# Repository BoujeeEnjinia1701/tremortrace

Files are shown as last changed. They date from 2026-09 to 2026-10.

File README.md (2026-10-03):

# TremorTrace

     

**Area:** BioMedical · **TRL:** 3 of 9 (proof of concept by calculation) · **Value-engineering target:** USD 150 (estimated cost USD 43.79) · **Difficulty:** 2 of 5

Wrist-worn IMU band that logs tremor frequency and amplitude continuously, with an open analysis notebook that produces a daily tremor profile.

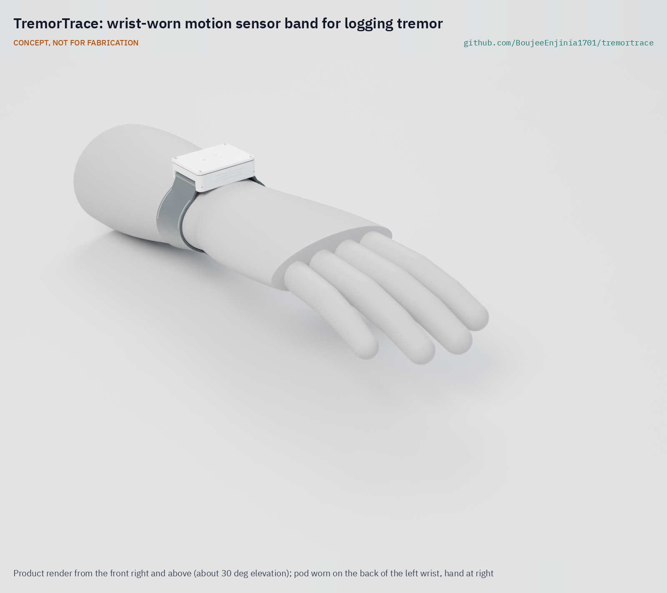
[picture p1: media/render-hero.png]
TremorTrace: wrist-worn motion sensor band for logging tremor, product render


[Exploded render](media/render-exploded.png) · [Detail render](media/render-detail.png) · [Interactive 3D model](media/viewer.html) · [Concept blueprint (PDF)](media/concept-blueprint.pdf) · [General arrangement (PDF)](cad/drawings/TRT-DWG-002.pdf) · [Calculations](docs/04-calcs/01-sizing.md) · [Prototype build plan](docs/05-build-plan.md) · [Design decisions](docs/06-design-decisions.md) · [Review note](docs/REVIEW.md)

## Concept rationale

Research groups have shown that a wrist-worn inertial sensor can follow tremor frequency and amplitude through a normal day, but most of that capability sits inside closed products or a single phone ecosystem. TremorTrace takes the smallest workable path: one off-the-shelf module with a built-in six-axis IMU, a coin-sized cell and a printed pod on a standard 22 mm watch strap. The band reduces each 10 s window to a 32-byte summary and keeps it on the wearer's own devices, so the data volume stays small and the privacy model stays simple.

Being open and garage-buildable matters because the people who most need a daily tremor record, and the researchers who want to study it, rarely control the tools. A design that costs about USD 44 in parts, needs no custom circuit board and publishes its analysis notebook can be built, inspected and adapted by a university lab, a patient group or a maker space anywhere. It is a research and educational prototype, not a medical device.

## Burning platform

Parkinson's disease is growing quickly. The [World Health Organization](https://www.who.int/news-room/fact-sheets/detail/parkinson-disease) estimates that over 8.5 million people were living with it in 2019 and that its prevalence has doubled in the past 25 years. Essential tremor is more common still: a worldwide meta-analysis put its pooled prevalence at 0.9 % at all ages and 4.6 % at age 65 and over ([Louis and Ferreira, Movement Disorders, 2010](https://movementdisorders.onlinelibrary.wiley.com/doi/10.1002/mds.22838)).

The specialists who judge tremor are scarce and unevenly spread. The WHO and World Federation of Neurology atlas found a median of 0.1 neurologists per 100,000 people in low-income countries against 7.1 in high-income countries ([WFN, 2017](https://wfneurology.org/2017-09-18-wcn-press-release-neurology-atlas)). Where a visit comes every few months, or not at all, a short observation in the room is all the evidence there is about how tremor behaves across a day.

## Where it could be used

### By industry

| Industry | Use |
| --- | --- |
| University research | Open, inspectable reference sensor for studies of tremor variation at home |
| Clinical research | Exploratory daily tremor profiles alongside established rating scales and diaries in research studies |
| Patient associations | Low-cost kits for members who want to see and share their own daily patterns |
| Biomedical engineering education | Teaching sampling, spectral analysis, power budgets and privacy-by-design on a real wearable |
| Open hardware and maker spaces | A reproducible wearable platform to adapt for other movement research |

### By country or region

| Country or region | Why it matters there |
| --- | --- |
| Netherlands | ParkinsonNet, founded in 2004, links about 3,000 allied health professionals in 69 regional networks ([Commonwealth Fund, 2016](https://www.commonwealthfund.org/publications/case-study/2016/dec/parkinsonnet-innovative-dutch-approach-patient-centered-care)); community therapists could use shared daily profiles between neurology visits |
| United States | Clinical trials have long used half-hourly home diaries to count daily motor states ([Hauser et al., 2000](https://pubmed.ncbi.nlm.nih.gov/10803796/)); an open sensor record gives researchers a comparison |
| China | A community survey found Parkinson's prevalence of 1.37 % above age 60, about 3.62 million people ([Qi et al., Movement Disorders, 2021](https://movementdisorders.onlinelibrary.wiley.com/doi/10.1002/mds.28762)) |
| Sub-Saharan Africa | The WHO African region reported about 0.1 neurologists per 100,000 people ([WFN, 2017](https://wfneurology.org/2017-09-18-wcn-press-release-neurology-atlas)); a low-cost local record can support the few specialist reviews available |
| India | The burden of non-communicable neurological disorders, Parkinson's disease among them, is rising mainly because the population is ageing, and the national study calls for addressing a shortage of trained neurologists ([ICMR, PHFI and IHME, 2021](https://www.icmr.gov.in/icmrobject/custom_data/1702892885_press_release_gbd_india_neurological_disorders_14072021.pdf)); a band built from widely sold modules suits university and community research groups |

## What sparked the idea

The starting point was the Parkinson's disease home diary developed by Robert Hauser and colleagues in 2000, in which people mark their predominant state for every half hour of the day on paper ([Hauser et al., Clinical Neuropharmacology, 2000](https://pubmed.ncbi.nlm.nih.gov/10803796/)). The diary was built as a patient-reported outcome for clinical trials and is still being validated today ([Löhle et al., npj Parkinson's Disease, 2022](https://www.nature.com/articles/s41531-022-00331-w)), and it shows both how much a day-long record is valued and how much it asks of the person keeping it. TremorTrace asks the same question of a wrist sensor instead: it writes a small entry every 10 seconds without any effort from the wearer and leaves the record in the wearer's hands.

## Problem

Tremor severity is scored during short clinic visits, which misses how it varies day to day.

## Concept

Wrist-worn IMU band that logs tremor frequency and amplitude continuously, with an open analysis notebook that produces a daily tremor profile.

Full design precis: [docs/02-concept.md](docs/02-concept.md)

## Key components

- Seeed XIAO nRF52840 Sense class module (nRF52840 BLE, 6-axis IMU, 2 MB flash, charger)
- 150 mAh protected LiPo cell
- Printed PETG enclosure with TPU gasket, 40 x 30 x 12 mm
- 22 mm woven textile strap, about 8 g

The priced bill of materials (USD 43.79 in parts, against a USD 150 value-engineering target) is in [bom/bom.csv](bom/bom.csv).

## Status at TRL 3

Calculations in [TRT-CAL-001](docs/04-calcs/01-sizing.md) show 0.1 Hz frequency resolution, 4.5 to 6.3 days per charge and 9.7 days of on-band history. Mass is 26.2 g against a 30 g limit with the textile strap adopted under [TRT-DDR-002](docs/decisions/0002-recommendations-accepted.md). The parametric model is [cad/src/model.py](cad/src/model.py) and the general arrangement is [TRT-DWG-002](cad/drawings/TRT-DWG-002.pdf), Rev P3. The design is constructable: every part can be made and fixed as drawn ([TRT-DDR-003](docs/decisions/0003-design-for-construction.md)). TRL 4 work is on hold.

## Building the prototype

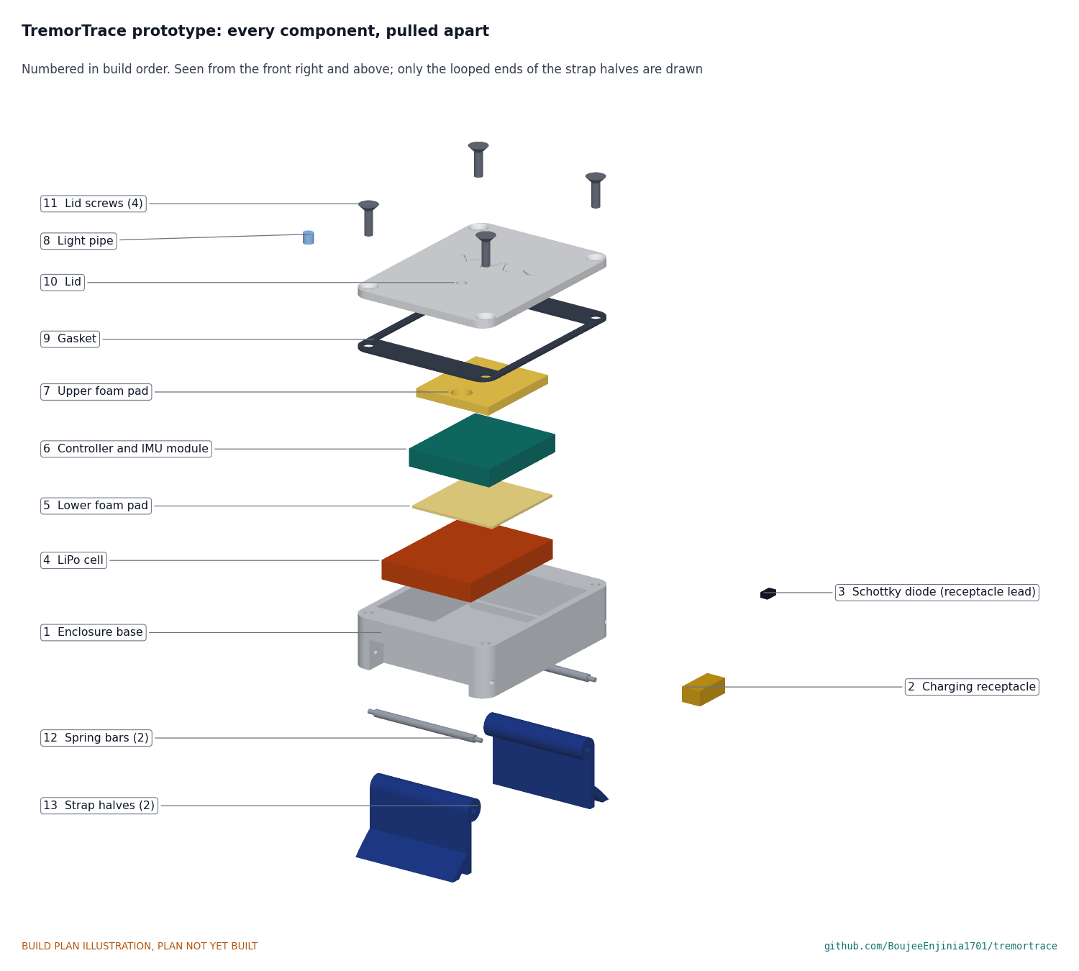
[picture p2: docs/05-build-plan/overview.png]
TremorTrace prototype: every component pulled apart and numbered in build order


The [prototype build plan](docs/05-build-plan.md) (TRT-BLD-001) shows, in pictures, how to make each of the thirteen components and put them together in nine steps; nothing has been built yet. The base, lid and gasket are 3D printed, two foam pads are cut from sheet, and the module, cell, charging receptacle, screws, spring bars and strap are bought; the electronics are four soldered wires and one small diode. Writing the plan made the design buildable: the spring bar holes, lid screws and strap notches were redesigned, and cell ribs, a glue collar for the charging receptacle and foam pads that let the lid clamp the stack were added (TRT-DDR-003, open for Amish's review). Every picture is drawn from the model, and the model checks that each part touches what it should and clears what it should not.

## Safety

> This is a research and educational prototype. It is not a medical device, has not been cleared or approved by any regulator, and must not be used to diagnose, treat or monitor any person.

## Repository layout

| Folder | Contents |
| --- | --- |
| `docs/` | Problem, concept, requirements, calculations, build plan and design decisions |
| `cad/src/` | build123d Python source, the source of truth for all geometry |
| `cad/step/`, `cad/stl/` | Exported models for FreeCAD, other CAD tools and printing |
| `cad/drawings/` | 2D sketches and dimensioned drawings |
| `bom/` | Bill of materials |
| `electronics/` | KiCad schematics and PCB layouts |
| `firmware/` | Microcontroller code |
| `media/` | Renders, perspectives and photos |
| `build-log/` | Dated prototyping notes |

## Documentation

Controlled documents follow the portfolio [documentation standard](.kit/STANDARDS.md). Each carries a document ID (TRT-PRC-001 for the precis), a version and a revision history. Branded PDFs are built with `python .kit/render.py` and attached to GitHub Releases when a document is tagged, for example `TRT-PRC-001/v1.0`.

## Credits

Designed by Amish Chadha, with contributions from Dr. Geeti Chadha. See [CONTRIBUTORS.md](CONTRIBUTORS.md) for roles. To cite this design, use [CITATION.cff](CITATION.cff) (GitHub shows it as "Cite this repository").

AI assistance (Claude) was used to accelerate concept renders, prototype documentation and first-pass sizing calculations. Design direction and all decisions are Amish Chadha's, recorded in this repository's decision records (`docs/decisions/`).

## Licenses

- **Hardware** (CAD, drawings, BOM, electronics): [CERN-OHL-S v2](LICENSE)
- **Software** (firmware, scripts, notebooks): [MIT](LICENSE-SOFTWARE)

A project of the [Design Molecule](https://designmolecule.com) lab.

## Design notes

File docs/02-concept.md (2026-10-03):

---
doc_id: TRT-PRC-001
title: TremorTrace design precis
project: TremorTrace
doc_type: Design precis
version: "0.8"
status: Draft
date: '2026-10-02'
author: Amish Chadha
license: CERN-OHL-S-2.0
revisions:
- version: "0.1"
  date: '2026-09-24'
  author: Amish Chadha
  change: Initial scaffold
- version: "0.2"
  date: '2026-09-24'
  author: Amish Chadha
  change: Populate to TRL 2 (architecture, first-order numbers, safety, media)
- version: "0.3"
  date: '2026-09-24'
  author: Amish Chadha
  change: 'Review fixes: one-module and local-first choices marked proposed; massing pod closed at 12 mm; concept sheet renumbered TRT-DWG-001'
- version: "0.4"
  date: '2026-09-25'
  author: Amish Chadha
  change: 'TRL 3: decisions from TRT-DDR-001 recorded; numbers from TRT-CAL-001 (storage ratio 390, not 1,000; firmware in internal flash; mass 29.4 g); parametric model and TRT-DWG-002'
- version: "0.5"
  date: '2026-09-25'
  author: Amish Chadha
  change: Recommendations accepted by Amish (DDR-002)
- version: "0.6"
  date: '2026-10-02'
  author: Amish Chadha
  change: 'Design for construction (TRT-DDR-003): lid screws, base features, mass and cost; budget as a value-engineering target'
- version: "0.7"
  date: '2026-10-02'
  author: Amish Chadha
  change: First partner and the activity-flag question answered by Amish's decisions of 2026-10-02 (TRT-DEC-001)
- version: "0.8"
  date: '2026-10-02'
  author: Amish Chadha
  change: 'Parts cost USD 43.79 with the Schottky diode (BOM line 12)'
---

# TremorTrace design precis

TremorTrace is a small wrist pod on a watch strap that records wrist motion all day, turns it into 10-second tremor summaries on the band, and hands them to an open notebook that draws a daily tremor profile. The TRL 3 calculations (TRT-CAL-001) show that one off-the-shelf module and a 150 mAh cell meet nine of eleven requirements for USD 43.79 in parts, including mass at 26.2 g against a 30 g limit with a textile strap; splash resistance and the notebook can only be verified with hardware and software work.

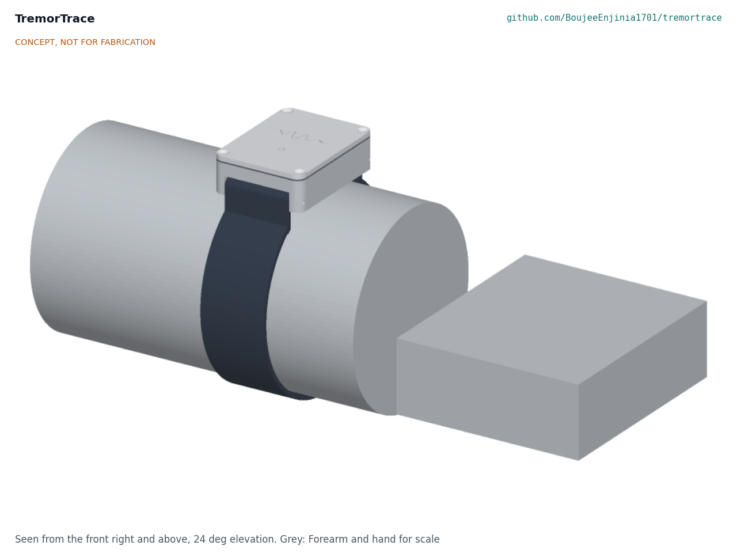
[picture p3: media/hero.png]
Hero render


## How it works

1. **Sense.** A 6-axis IMU (accelerometer and gyroscope) samples wrist motion at 104 Hz, with ranges of +/-8 g and +/-2000 dps.
2. **Summarize on the band.** Every 10 seconds the firmware band-pass filters the signal to 3 to 15 Hz, runs a spectrum, and stores a 32-byte summary: dominant frequency, band RMS of acceleration and angular velocity, total RMS, a band-to-low-frequency power ratio and an activity flag. Tremor values are kept even when the flag says the wearer was moving, so tremor during activity is not lost.
3. **Store.** Summaries go to the module's 2 MB flash, enough for 9.7 days at 16 h of wear per day without a phone. A 256 kB area holds up to 21 raw 10 s snippets captured on demand for research.
4. **Sync.** When the owner opens the web Bluetooth page or a laptop script, summaries transfer over Bluetooth Low Energy. Nothing goes to the cloud.
5. **Analyze.** An open Python notebook turns summaries into a daily profile: minutes of tremor per hour, dominant frequency and amplitude over the day, and optional medication-time markers entered by the owner.

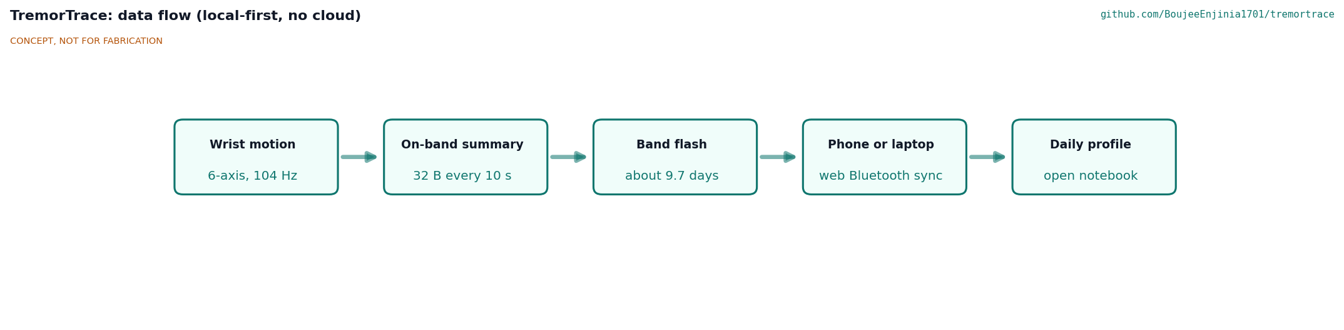
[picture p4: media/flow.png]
System and data flow


## Main components

Table 1. Main components; item numbers match `bom/bom.csv` and the exploded view.

| # | Component | Choice | Notes |
| --- | --- | --- | --- |
| 1 | Strap | 22 mm woven textile two-piece quick-release strap | Skin-safe and washable; the heaviest part (about 8 g, assumed). Replaced the 12 g silicone strap; decided by Amish, 2026-09-25 (TRT-DDR-002) |
| 2 | Enclosure lid | 3D-printed PETG, 1.5 mm, four M2 countersunk screws, one in each lug horn | 2 mm light pipe over the module's status LED |
| 3 | Controller and IMU | Seeed XIAO nRF52840 Sense class: nRF52840, LSM6DS3TR-C IMU, 2 MB flash, BQ25101 charger | One module, no custom PCB. Decided by Amish, 2026-09-25 (TRT-DDR-001) |
| 4 | Battery | 150 mAh protected LiPo, 19.75 x 26.02 x 3.8 mm (Adafruit 1317 class) | See power budget |
| 5 | Enclosure base | 3D-printed PETG with integrated 22 mm lugs, cell locating ribs and a glue collar | Charging connector glued through the floor |
| 6 | Charging contacts | Magnetic 2-pin pogo connector | Keeps the enclosure sealed |
| 7 | Gasket | Printed TPU ring, 0.5 mm compressed | Toward the IP54 target (R7) |
| 8 | Spring bars | 22 mm | Hold the strap in the lugs |

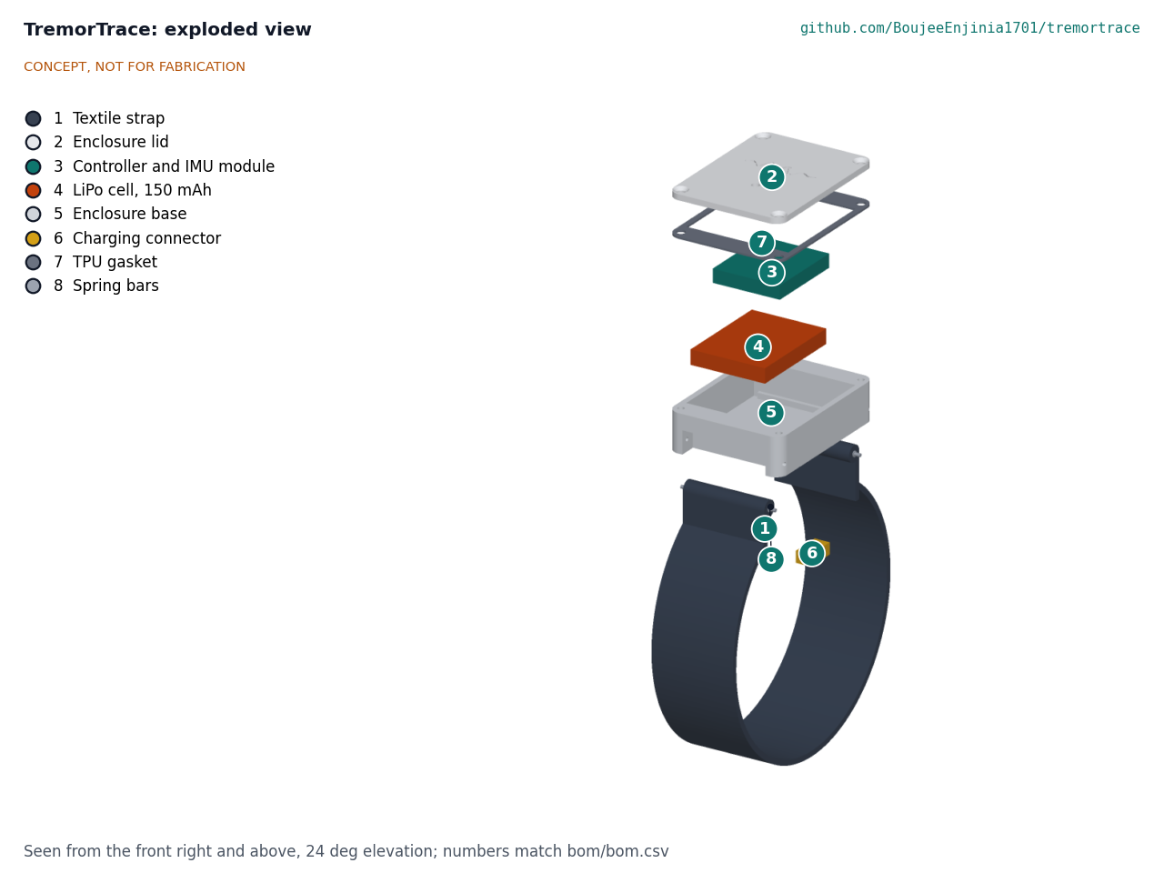
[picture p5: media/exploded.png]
Exploded view


## Key numbers

All values come from TRT-CAL-001 and the parametric model in `cad/src/model.py`.

Table 2. Key numbers at TRL 3.

| Quantity | Value | Requirement |
| --- | --- | --- |
| Frequency resolution | 0.100 Hz bins (10 s at 104 Hz) | R1 (0.2 Hz) met, with sample-rate correction |
| Nyquist limit | 52 Hz | R1, R3 met |
| In-band noise | 0.31 mg and 0.017 dps RMS | R2 met |
| Recording current | 1.12 mA nominal, 1.54 mA conservative | |
| Battery life | 6.3 days nominal, 4.5 days conservative | R4 (3 days) met, if the firmware sleeps |
| Summary storage | 184.3 kB per day (32 bytes per 10 s, 16 h) | |
| On-band history | 9.7 days | R5 (7 days) met |
| Pod size | 40 x 30 x 12 mm | R6 size met |
| Mass | 26.2 g with textile strap | R6 (30 g) met, 3.8 g margin |
| Parts cost | USD 43.79, USD 106.21 under the USD 150 value-engineering target | R10 met |

The general arrangement is drawing TRT-DWG-002 (`cad/drawings/TRT-DWG-002.pdf`), Rev P3. How to build the prototype is in the build plan TRT-BLD-001 (`docs/05-build-plan.md`); the changes that made the design buildable are in TRT-DDR-003.

## Key design choices

- **Summaries, with optional raw snippets.** A 32-byte summary is 390 times smaller than the 12,480 bytes of raw data in a 10 s window, and it keeps personal data minimal. Decided by Amish, 2026-09-25 (TRT-DDR-001).
- **One module, no custom PCB.** Keeps the first build within reach of anyone with a soldering iron and a 3D printer. Decided by Amish, 2026-09-25 (TRT-DDR-001).
- **Web Bluetooth page first.** No app store and no account; a native app may follow. Decided by Amish, 2026-09-25 (TRT-DDR-001).
- **Local-first data.** No cloud account is needed to use or analyze the data (R9). Decided by Amish, 2026-09-25 (TRT-DDR-001).
- **Most affected wrist first.** Decided by Amish, 2026-09-25 (TRT-DDR-001).
- **Charge current 50 mA.** Charges in about 3.6 h with about 65 mW of charger heat, against 1.8 h and 130 mW at 100 mA. The firmware selects the 50 mA setting. Decided by Amish, 2026-09-25 (TRT-DDR-002).
- **Textile strap.** A woven textile strap of about 8 g replaces the 12 g silicone strap and raised the R6 mass margin from 0.6 g to 4.6 g (3.8 g after the parts added for construction). Decided by Amish, 2026-09-25 (TRT-DDR-002).

## Safety

> **Safety:** Research and educational prototype only. It is not a medical device, has not been cleared or approved by any regulator, and must not be used to diagnose, treat or adjust medication.

- The LiPo cell sits against the skin: use a protected cell, never charge while worn, charge at no more than the cell's 150 mA limit, and stop use if the pod becomes warm or swollen.
- Use skin-safe strap materials and check for irritation during long wear.
- Tremor data is health data. Keep it on the owner's devices and share only with consent.

## Open questions

- The activity flag marks tremor during a reach as activity in synthetic data (TRT-CAL-001, section 4). How well can action tremor be separated from voluntary movement with 10 s summaries? Decided by Amish, 2026-10-02: keep the flag, report tremor with and without it, and choose a classifier at TRL 4 from recorded data.
- Confirm the IMU sample-rate tolerance, the module's run current and the textile strap mass.
- First clinical or patient partner for co-design and eventual validation. Decided by Amish, 2026-10-02 (TRT-DEC-001): the first candidate to approach is an academic movement disorders clinic with its own ethics board, introduced through the OpenRatio network, with the International Essential Tremor Foundation as the route to participants, shared with StillBand and SteadySleeve; not yet approached.

Open decisions are tracked in the design decisions register, TRT-DEC-001 (`docs/06-design-decisions.md`).

Concept media: [blueprint sheet](../media/concept-blueprint.pdf), [interactive 3D model](../media/viewer.html).

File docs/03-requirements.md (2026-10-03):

---
doc_id: TRT-REQ-001
title: TremorTrace requirements
project: TremorTrace
doc_type: Requirements
version: "0.6"
status: Draft
date: '2026-10-02'
author: Amish Chadha
license: CERN-OHL-S-2.0
revisions:
- version: "0.1"
  date: '2026-09-24'
  author: Amish Chadha
  change: Initial scaffold
- version: "0.2"
  date: '2026-09-24'
  author: Amish Chadha
  change: First measurable requirements for TRL 2
- version: "0.3"
  date: '2026-09-25'
  author: Amish Chadha
  change: 'Apply TRT-DDR-001 decisions: R5 redefined with a raw-snippet reserve, R11 names the LED and web Bluetooth page, wrist choice; status from TRT-CAL-001'
- version: "0.4"
  date: '2026-09-25'
  author: Amish Chadha
  change: Recommendations accepted by Amish (DDR-002)
- version: "0.5"
  date: '2026-10-02'
  author: Amish Chadha
  change: 'Design for construction (TRT-DDR-003): R6 and R10 figures; budget as a value-engineering target'
- version: "0.6"
  date: '2026-10-02'
  author: Amish Chadha
  change: 'R10 cost restated with the Schottky diode (USD 43.79); no status changed'
---

# TremorTrace requirements

These requirements were checked by calculation in TRT-CAL-001 (TRL 3). Nine are met by calculation or design review and R7 and R8 cannot be verified on paper; none is not met. Changes in v0.3 follow Amish's decisions of 2026-09-25 (TRT-DDR-001). In v0.4, R6 moves from at risk to met because the textile strap recommended at TRL 3 was accepted (TRT-DDR-002), and R4 names the 50 mA charge setting. In v0.5 the mass and cost figures follow the constructable design (TRT-DDR-003) and the budget is treated as a value-engineering target; no status changes.

Table 1. Requirements and TRL 3 status.

| ID | Requirement | Target | Verification (TRL 3 or later) | TRL 3 status (TRT-CAL-001) |
| --- | --- | --- | --- | --- |
| R1 | Measure tremor frequency across the clinically relevant band | 3 to 15 Hz, resolution 0.2 Hz or better | Calculation of sampling and window length; later bench shaker test | Met, if the firmware corrects the sample rate against the crystal |
| R2 | Measure tremor amplitude | Acceleration RMS and angular velocity RMS in the tremor band, reported per window | Calculation; later comparison against a reference sensor | Met |
| R3 | Sample motion fast enough | 6-axis IMU at 100 Hz or more | Datasheet and firmware configuration | Met |
| R4 | Run a full waking day and more | 3 days or more between charges at 16 h per day of wear; recharge at the 50 mA setting | Power budget calculation | Met, 4.5 to 6.3 days, if the firmware sleeps |
| R5 | Store a week of results on the band | 7 days of 10 s window summaries at 16 h of wear per day without a phone, alongside a reserved area for on-demand raw snippets | Storage calculation | Met, 9.7 days |
| R6 | Comfortable for all-day wear | Mass 30 g or less including strap; pod no larger than 45 x 35 x 14 mm | Massing model, then weighing | Met: 26.2 g with textile strap (TRT-CAL-001 v0.3); size met |
| R7 | Skin-safe and wearable | Silicone or textile strap; no exposed electronics; splash resistant (IP54 target) | Design review | Not verifiable at TRL 3 |
| R8 | Produce a daily tremor profile | Open notebook turning window summaries into a daily chart of tremor time, frequency and amplitude | Run on sample data | Not verifiable at TRL 3 |
| R9 | Protect health data | Data stored locally and exported only by the owner; no cloud dependency | Design review | Met (design review) |
| R10 | Low cost and buildable | Parts cost reported against the USD 150 value-engineering target; no custom PCB required for the first build | Priced BOM | Met: USD 43.79, USD 106.21 under the target |
| R11 | Clear status | Status LED on the band and the web Bluetooth page show battery, recording and sync state | Design review | Met (design review) |

## Assumptions

- Parkinsonian rest tremor is typically about 4 to 6 Hz and essential tremor about 4 to 12 Hz; a 3 to 15 Hz band covers both with margin.
- Wear time of 16 h per day and nightly charging is acceptable, but a multi-day battery is preferred so a missed charge does not lose a day.
- One band is worn on the most affected wrist (decided by Amish, 2026-09-25, TRT-DDR-001); both wrists are later work.
- The mass limit in R6 includes the strap. The strap is a woven textile strap of about 8 g (TRT-DDR-002) and remains the least certain item in the mass estimate.

> **Safety:** TremorTrace is a research and educational prototype, not a medical device. It carries a lithium polymer cell against the skin; the cell must be protected and must never be charged while the band is worn.

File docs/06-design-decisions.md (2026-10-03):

---
doc_id: TRT-DEC-001
title: TremorTrace design decisions register
project: TremorTrace
doc_type: Design decisions register
version: "0.3"
status: Draft
date: '2026-10-02'
author: Amish Chadha
license: CERN-OHL-S-2.0
revisions:
- version: "0.1"
  date: '2026-10-02'
  author: Amish Chadha
  change: Register opened; open decisions from the review note, the decision records and the build plan work
- version: "0.2"
  date: '2026-10-02'
  author: Amish Chadha
  change: Amish approved the recommendations for open items 1 to 10 on 2026-10-02 (TRT-DDR-003 accepted, with A1 and A2); moved to decisions made
- version: "0.3"
  date: '2026-10-02'
  author: Amish Chadha
  change: 'Cost restated with the diode (BOM line 12): USD 43.79'
---

# TremorTrace design decisions register

Every design decision still to be made, and every decision made, in one place. Each decision is argued in full in its decision record under `docs/decisions/` or in the review note (`docs/REVIEW.md`); this register is the index Amish works from. The build plan (`docs/05-build-plan.md`) describes the design as it stands and does not list open decisions.

> **Safety:** TremorTrace is a research and educational prototype, not a medical device. It has not been cleared or approved by any regulator and must not be used to diagnose, treat or monitor any person.

## Open decisions

None. All open decisions were decided on 2026-10-02.

## To confirm when parts are bought

| # | What to confirm | Why it matters | Source |
| --- | --- | --- | --- |
| 1 | The status LED position on the module | It sets the light pipe bore (6.5 mm from the centre on the centre line) and the hole in the upper foam pad | TRT-DDR-003, C6 and C8 |
| 2 | The module's thickness with its components (3.5 mm assumed) | It sets the squeeze on the upper foam pad; more than 4.5 mm would need a thinner pad | TRL 3 model; TRT-CAL-001, section 7 |
| 3 | The charging receptacle's body size (4 x 8 x 3 mm assumed) and whether it has a flange | It sets the floor opening and the glue collar | TRT-DDR-003, C4 |
| 4 | The spring bars' tip diameter (about 0.9 mm) | The horn holes are drilled 1.0 mm; tips over 1.0 mm need a larger drill | TRT-DDR-003, C1 |
| 5 | That the module's 5 V pin carries no voltage with the cell connected and no charger | The receptacle contacts touch the skin; a Schottky diode is fitted in any case (decided 2026-10-02), and this check decides whether it can ever be dropped | TRT-DDR-003, A2 |
| 6 | That a printed horn takes an M2 thread-forming screw without splitting (1.2 mm of plastic round the screw) | If it splits, print the horns hotter or use M1.6 screws | TRT-DDR-003, C2 |
| 7 | The textile strap's mass (8 g assumed) and that its ends loop round a 1.5 mm bar inside a 4.5 mm notch | Mass margin under R6 is 3.8 g; the loop clearance is 0.35 mm | TRT-CAL-001, section 7; TRT-DDR-003, C3 |
| 8 | The IMU sample-rate tolerance and the module's run current | They carry the R1 and R4 results | TRT-CAL-001, sections 2 and 5 |

## Value engineering

Value-engineering target: USD 150 (a hypothetical control target, not a limit). Estimated cost of the constructable design: USD 43.79 (USD 106.21 under the target). Main cost drivers and savings worth trying:

- The largest lines are the controller and IMU module (USD 15.99), the textile strap (USD 10.00), the magnetic charging receptacle with its cable (USD 6.00) and the LiPo cell (USD 5.95); together they are USD 37.94 of the USD 43.79.
- Making the design constructable added USD 0.50 (two more lid screws); the foam pads and epoxy fall within the existing consumables allowance.
- Savings worth trying: a generic 22 mm textile strap (often under USD 5); buying the charging receptacle and cable as a bulk pair; the module price in small quantities from a distributor.

## Decisions made

| Date | Decision | Decided by | Record |
| --- | --- | --- | --- |
| 2026-09-25 | D1 single nRF52840 module with built-in IMU, no custom PCB; D2 10 s summaries with optional raw snippets; D3 web Bluetooth page first; D4 most affected wrist first; D5 local-first data | Amish: "proceed with all of your recommendations across all batches. Make sure we don't proceed to TRL 4 on any of them." | TRT-DDR-001 |
| 2026-09-25 | D6 charge at the 50 mA setting; D7 woven textile strap of about 8 g | Amish: "i accept all your recommendations, go with them across all repos." | TRT-DDR-002 |
| 2026-09-30 | Make the design physically buildable while drawing the build plan; keep open decisions out of the build plan | Amish: "If you are realising that the design cannot be built as per concept - fix the design assumptions to match and be physically feasible as you draw the illustrations." The changes were accepted on 2026-10-02 (below) | TRT-DDR-003 |
| 2026-10-01 | Treat `budget_usd` as a value-engineering target, not a limit | Amish: "the budgets are a hypothethical control target to ensure we are thinking along a value engineering lens" | `.kit/STANDARDS.md`, section 18 |
| 2026-10-02 | Design for construction accepted: the changes C1 to C9 of TRT-DDR-003, as made | Amish: "APPROVED: The open decisions from the last wave (TremorTrace to ZeerBox) came in after the review and aren't on the page either." | TRT-DDR-003, Table 1 |
| 2026-10-02 | Firmware update route: over Bluetooth with the nRF52840's over-the-air bootloader; opening the pod, with a new gasket, is kept for recovery only | Amish: "APPROVED: The open decisions from the last wave (TremorTrace to ZeerBox) came in after the review and aren't on the page either." | TRT-DDR-003, A1 |
| 2026-10-02 | Skin-side charging contacts: a small Schottky diode is fitted in the receptacle's positive lead on every band, and the bought module's 5 V pin is still checked dead with the cell connected and no charger; the diode is dropped only if measurements show the pin dead in every operating state | Amish: "APPROVED: The open decisions from the last wave (TremorTrace to ZeerBox) came in after the review and aren't on the page either." | TRT-DDR-003, A2 |
| 2026-10-02 | First co-design and validation partner: the first candidate to approach is an academic movement disorders clinic with its own ethics board, introduced through the OpenRatio network, with the International Essential Tremor Foundation as the route to participants, shared with StillBand and SteadySleeve. No prototype is worn without clinical oversight and ethics approval | Amish: "APPROVED: The open decisions from the last wave (TremorTrace to ZeerBox) came in after the review and aren't on the page either." | TRT-DDR-001, O1; TRT-DDR-002 |
| 2026-10-02 | OpenRatio confirmed as a named possible partner, described in soft, non-clinical wording as a research and educational network, not a clinical service | Amish: "APPROVED: The open decisions from the last wave (TremorTrace to ZeerBox) came in after the review and aren't on the page either." | TRT-DDR-001, O2 |
| 2026-10-02 | Kit 1.3.1 approved: concept media for small objects show a forearm for scale instead of the 1.75 m person | Amish: "APPROVED: The open decisions from the last wave (TremorTrace to ZeerBox) came in after the review and aren't on the page either." | TRT-DDR-001, O3 |
| 2026-10-02 | Strap path: the circular strap stays in the parametric model for the drawing and mass; the elliptical wrist path is used in renders only | Amish: "APPROVED: The open decisions from the last wave (TremorTrace to ZeerBox) came in after the review and aren't on the page either." | `docs/REVIEW.md`, 2026-09-26, item 1 |
| 2026-10-02 | Lid mark and grip ribs kept as printed-in features at no cost, with the mark debossed 0.4 mm (two 0.2 mm layers) into the 1.5 mm lid | Amish: "APPROVED: The open decisions from the last wave (TremorTrace to ZeerBox) came in after the review and aren't on the page either." | `docs/REVIEW.md`, 2026-09-26, item 3 |
| 2026-10-02 | Module detail and charging lead in the renders accepted as illustration only | Amish: "APPROVED: The open decisions from the last wave (TremorTrace to ZeerBox) came in after the review and aren't on the page either." | `docs/REVIEW.md`, 2026-09-26, item 4 |
| 2026-10-02 | Tremor during a reach: the separate activity flag is kept and tremor is reported both with and without it; a classifier is chosen at TRL 4 from recorded data | Amish: "APPROVED: The open decisions from the last wave (TremorTrace to ZeerBox) came in after the review and aren't on the page either." | TRT-CAL-001, section 4; TRT-PRC-001 |

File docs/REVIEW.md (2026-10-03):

# Review note: TremorTrace

## Session 2026-09-24: /populate to a strong TRL 2 (pilot run from Cowork)

### What was done

- `docs/01-problem.md` (TRT-PRB-001 v0.2): users and context, constraints, out of scope, prior research with links.
- `docs/03-requirements.md` (TRT-REQ-001 v0.2): 11 measurable requirements (R1 to R11) with targets and planned verification.
- `docs/02-concept.md` (TRT-PRC-001 v0.2): how it works, main components, first-order numbers, design choices, safety, open questions.
- `cad/src/concept_media.py`: massing model (strap, enclosure, module, LiPo cell, contacts) with a forearm and hand for scale.
- `media/`: hero, blueprint sheet (PNG and PDF), cutaway, exploded view with BOM callouts, data flow diagram, `model.glb` and `viewer.html`.
- `bom/bom.csv`: seven lines with indicative prices, numbered to match the exploded view; `bom/bom-notes.md`.
- `docs/pdf/`: branded PDFs of the three controlled documents.

### Key results (estimates, to be checked at TRL 3)

| Quantity | Estimate | Requirement |
| --- | --- | --- |
| Frequency resolution | 0.1 Hz (10 s window at 104 Hz) | R1 met |
| Battery life | about 4 days on 150 mAh | R4 met, thin margin |
| On-band history | about 10 days of summaries | R5 met |
| Mass | about 22 g with strap | R6 met |
| Parts cost | about $40 | R10 met |

No requirement is known to be missed. R4 depends on IMU current in the chosen module, which is unverified.

### Proposed, awaiting Amish

1. Controller: a single nRF52840 module with built-in IMU (Seeed XIAO nRF52840 Sense class). Alternative: separate nRF52 module and IMU breakout (more wiring, more flexibility). Decided by Amish, 2026-09-25: go with recommendation (TRT-DDR-001).
2. Store 10-second summaries rather than raw data, with optional raw snippets for research. Decided by Amish, 2026-09-25: go with recommendation (TRT-DDR-001).
3. Phone route: a web Bluetooth page first, native app later. Decided by Amish, 2026-09-25: go with recommendation (TRT-DDR-001).
4. Wear on the most affected wrist first; both wrists later. Decided by Amish, 2026-09-25: go with recommendation (TRT-DDR-001).
5. First co-design and validation partner: a movement disorders clinic, a patient association, or the OpenRatio network.

### Safety concerns

- Not a medical device; the documents say so and must keep saying so.
- LiPo cell against skin: protected cell, no charging while worn.
- Tremor data is health data: local-first design, owner-controlled sharing.

### Recommended next step

Review this note and the media. If approved, run `/advance-trl3` to verify the power budget, frequency analysis and activity flag by calculation and produce the parametric model and drawing sheet.

## Session 2026-09-24: review fixes

At Amish's request, after a review of commits `15c42b7` and `5091eea`:

- `cad/src/concept_media.py`: the massing pod had no side walls between base and lid, and stacked to 13.5 mm against the 12 mm in TRT-PRC-001. The base walls now enclose the cell and module, and the pod is 12.0 mm overall. All media regenerated.
- The concept sheet is renumbered TRT-DWG-001 (it was TRT-DWG-010); drawing numbers start at 001 (`.kit/STANDARDS.md`, section 1).
- TRT-PRC-001 v0.3: "One module, no custom PCB" and "Local-first data" are now marked "Proposed, awaiting Amish", as `CLAUDE.md` section 2 requires.

Still awaiting Amish: approval of kit 1.3.1, whose forearm-for-scale rule for small objects replaces the 1.75 m person that `/populate` asks for, and confirmation of "OpenRatio" as a possible co-design partner.

## Session 2026-09-25: TRL 3

Authority: on 2026-09-25 Amish wrote "proceed with all of your recommendations across all batches. Make sure we don't proceed to TRL 4 on any of them." This session advanced TremorTrace from TRL 2 to TRL 3 and stopped there.

### What was done

- `docs/decisions/0001-trl2-review-decisions.md` (TRT-DDR-001 v0.1): the TRL 2 review decisions, and the items still open.
- `docs/04-calcs/01-sizing.md` (TRT-CAL-001 v0.1) and `docs/04-calcs/sizing.py`: sampling, noise and range, a synthetic check of the 10 s window algorithm and the activity flag, power budget, storage, size and mass (read from the model), and cost (read from the BOM).
- `cad/src/model.py`: parametric build123d model (pod base with integrated 22 mm lugs, gasket, lid, cell, module, charging connector, spring bars, strap). Exports `cad/step/tremortrace-{pod-assembly,on-strap,base,lid,gasket}.step` and `cad/stl/tremortrace-{pod-assembly,base,lid,gasket}.stl`.
- `cad/src/sheets.py` and `cad/drawings/TRT-DWG-002.{svg,pdf,png}`: general arrangement at Rev P1, 2:1, marked "CONCEPT, NOT FOR FABRICATION" and "PRELIMINARY, NOT FOR FABRICATION".
- `bom/bom.csv`: 11 lines, every line priced, $41.19 per band; `bom/bom-notes.md` updated.
- `cad/src/concept_media.py` now builds the media from `model.py`; all media regenerated and inspected (hero, blueprint TRT-DWG-001, cutaway, exploded view with items 1 to 8, flow, `model.glb`).
- TRT-REQ-001 v0.3, TRT-PRB-001 v0.3 and TRT-PRC-001 v0.4 updated for the decisions and the calculated numbers. The precis was already at v0.3, so it moved to v0.4 rather than 0.3.
- `project.yaml`: `trl: 3`, `trl_target: 3`, evidence listed. `README.md`: TRL 3 badge and status.

### Requirement status (TRT-CAL-001)

Not met: none. At risk and not verifiable first:

| ID | Status | Value |
| --- | --- | --- |
| R6 | At risk (mass); size met | 29.4 g against 30 g, strap assumed 12 g; pod 40 x 30 x 12 mm |
| R7 | Not verifiable at TRL 3 | Gasketed pod; IP54 needs a test |
| R8 | Not verifiable at TRL 3 | Summary record defined; notebook not written |
| R1 | Met, conditional | 0.100 Hz bins; needs sample-rate correction against the 32.768 kHz crystal (up to 0.30 Hz error otherwise) |
| R4 | Met, conditional | 6.3 days nominal, 4.5 days conservative; 0.69 days if the firmware never sleeps |
| R5 | Met | 9.7 days; 6.4 days if the band logged 24 h per day |
| R2, R3, R9, R10, R11 | Met | Noise floor 0.31 mg RMS; 104 Hz; local-first; $41.19; LED and web Bluetooth page |

Corrections to TRL 2 numbers: the summary-to-raw ratio is 390, not about 1,000; firmware sits in the nRF52840's internal flash, so all 2 MB of external flash holds data; the mass estimate rose from 22 g to 29.4 g once the enclosure was modeled (7.0 g, not 5 g) and the cell mass taken from its listing (4.65 g).

Finding: the simple activity flag (low-frequency power greater than tremor-band power) marks tremor during a reach as activity in synthetic data, which would undercount action tremor in essential tremor. The design now keeps tremor values in every record and stores the flag separately.

### Decisions recorded (TRT-DDR-001)

Decided by Amish, 2026-09-25, going with the recommendation: D1 single nRF52840 module with built-in IMU, no custom PCB; D2 summaries with optional raw snippets; D3 web Bluetooth page first; D4 most affected wrist first; D5 local-first data. No budget or pitch change was recommended, so `budget_usd` stays at 150 and the pitch is unchanged.

### Still awaiting Amish

1. First co-design and validation partner (clinic, patient association or OpenRatio network). No recommendation was made.
2. Confirmation of OpenRatio as a possible partner.
3. Approval of kit 1.3.1 (forearm-for-scale rule for small objects). No recommendation was stated.
4. New: charge current 50 mA (recommended; 0.33 C, about 65 mW charger heat) or 100 mA. Decided by Amish, 2026-09-25: go with recommendation (TRT-DDR-002).

### Safety concerns

- Not a medical device; every document says so.
- LiPo cell against the skin: protected cell, never charge while worn, charge at or below the cell's 150 mA limit. The linear charger dissipates about 65 mW at 50 mA and 130 mW at 100 mA inside a sealed pod.
- Tremor data is health data; the design has no cloud path.

### Citations

The TRL 2 note listed no unchecked citations. This session checked the LSM6DS3TR-C figures (ST product page and datasheet), the XIAO nRF52840 figures (Seeed wiki) and the Adafruit 1317 cell (product page) on the web and cites them in TRT-CAL-001, section 9. The XIAO unit price could not be confirmed and stays indicative. Values marked "assumed" in TRT-CAL-001 have no source.

### TRL 4 material

None found. `build-log/` holds only its README; `electronics/` and `firmware/` are empty.

### Recommended next step

TRL 4 is on hold by Amish's instruction; do not start it. Paper work that remains within TRL 3: decide the four open items above, and choose a lighter strap (textile, about 8 g) to restore mass margin under R6 if Amish agrees. Decided by Amish, 2026-09-25: go with recommendation (TRT-DDR-002).

For reference only, TRL 4 would need: a built band, a bench shaker test of frequency and amplitude against a reference sensor (R1, R2), a measured current profile (R4), a splash test (R7), the analysis notebook run on recorded data (R8), weighing (R6), a lab test report (TST with `environment: lab`) and build log entries.

## Session 2026-09-25: recommendations accepted

Authority: on 2026-09-25 Amish wrote "i accept all your recommendations, go with them across all repos." Every open item with a recommendation is now "Decided by Amish, 2026-09-25: go with recommendation" and is recorded in `docs/decisions/0002-recommendations-accepted.md` (TRT-DDR-002 v0.1).

### Decisions applied and what changed

| # | Decision | Before | After |
| --- | --- | --- | --- |
| D6 | Charge current 50 mA (was TRT-DDR-001 O4) | Proposed, 50 or 100 mA | 50 mA as a firmware rule; about 3.6 h, about 65 mW charger heat |
| D7 | Woven textile strap, 22 mm | Silicone, 12 g, $8.00, 2.5 mm thick in the model | Textile, 8 g, $10.00, 1.4 mm thick in the model |
| | Resulting mass (R6) | 29.4 g, 0.6 g margin, at risk | 25.4 g, 4.6 g margin, met |
| | Parts cost (R10) | $41.19 | $43.19 |
| | Budget (`project.yaml`) | $150 | $150 (no change recommended) |

Files changed: `bom/bom.csv`, `bom/bom-notes.md`, `cad/src/model.py` (STEP and STL re-exported), `cad/src/sheets.py` (TRT-DWG-002 Rev P1 to P2), `cad/src/concept_media.py` (media regenerated), `docs/04-calcs/sizing.py`, TRT-CAL-001 v0.1 to v0.2, TRT-REQ-001 v0.3 to v0.4, TRT-PRC-001 v0.4 to v0.5, TRT-DDR-001 v0.1 to v0.2 (O4 marked decided), new TRT-DDR-002 v0.1, `project.yaml` (DDR-002 added to TRL evidence), `README.md`.

Also in this session: all generated files (document PDFs, drawing sheets, concept media) were regenerated so the footers carry designmolecule.com, and the README gained the sections "Concept rationale", "Burning platform", "Where it could be used" and "What sparked the idea". The inspiration point is the Parkinson's disease home diary of Hauser et al. (2000), with cited sources.

### Requirement status (TRT-CAL-001 v0.2)

Not met: none. At risk: none.

| ID | Status | Value |
| --- | --- | --- |
| R7 | Not verifiable at TRL 3 | Gasketed pod; IP54 needs a test |
| R8 | Not verifiable at TRL 3 | Summary record defined; notebook not written |
| R1 | Met, conditional | 0.100 Hz bins; needs sample-rate correction against the crystal |
| R4 | Met, conditional | 6.3 days nominal, 4.5 days conservative, if the firmware sleeps |
| R6 | Met | 25.4 g against 30 g; pod 40 x 30 x 12 mm |
| R2, R3, R5, R9, R10, R11 | Met | 0.31 mg noise floor; 104 Hz; 9.7 days; local-first; $43.19; LED and web Bluetooth page |

### Still awaiting Amish (no recommendation was made)

1. O1: first co-design and validation partner (clinic, patient association or OpenRatio network).
2. O2: confirmation of OpenRatio as a possible partner.
3. O3: approval of kit 1.3.1 (forearm-for-scale rule for small objects).

### Cross-repo actions

None. Neither decision needs a change in another repo.

### Safety concerns

Unchanged: not a medical device; protected LiPo cell, never charged while worn, charged at the 50 mA setting; tremor data stays local. A textile strap absorbs sweat and should be washable and checked for skin irritation.

### TRL 4

TRL 4 remains on hold by Amish's instruction. Nothing was built, bought, tested or programmed. `trl: 3` and `trl_target: 3` are unchanged.

## Session 2026-09-26: sources strengthened

- `README.md`, "Where it could be used", India row: the row had no citation. It now cites the ICMR, PHFI and IHME release of 14 July 2021 on the India State-Level Disease Burden Initiative study of neurological disorders (1990 to 2019), which reports that the burden of non-communicable neurological disorders, including Parkinson's disease, is rising mainly through population ageing and calls for addressing the shortage of trained neurology workforce. The unsourced claim that specialist care is concentrated in cities was removed.
- All other links in the four README source sections were re-fetched and confirmed (WHO, Louis and Ferreira 2010, WFN 2017, Commonwealth Fund 2016, Qi et al. 2021, Löhle et al. 2022, which also confirms the Hauser et al. 2000 diary). The inspiration (Hauser home diary) is unchanged. No controlled documents changed.

## Session 2026-09-26: product appearance model and photoreal renders

Amish chose this repo for the first batch of product renders on 2026-09-26. This session adds an appearance model for photoreal renders; it changes no design value, requirement, calculation or controlled document.

### What was done

- New `cad/src/product_model.py` (`product_parts()`, `TITLE`, `RENDER_VIEWS`). It imports `PARAMS`, `_derived()` and `build_parts()` from `cad/src/model.py` and keeps every main dimension and interface: pod 30 x 40 x 12 mm, 22 mm lugs, spring bar axes, gasket seat, screw positions, light pipe bore, charging opening and the internal envelopes.
- `README.md`: hero image now points to `media/render-hero.png`, with a link to `media/render-exploded.png`. The render files are produced separately.

What the appearance model adds (28 parts: 15 shell, 10 internal, 2 accessory, 1 context):

- Filleted base (0.6 mm underside edge, 0.4 mm top rim) and lid (1.0 mm top edge), so the dark TPU gasket reads as the parting line.
- Three shallow grip ribs on each X face of the base.
- Pan-head M2 lid screws with a cross recess, sitting in shallow seats in the lid.
- Status light pipe shown lit (emissive), plus the module's status LED.
- A raised tremor-trace mark (a short decaying wave) on the lid in the kit accent, #0F766E.
- Visible internals: module PCB with RF shield, USB-C, ICs and castellated pads; foam pad; LiPo cell with protection tape; magnetic charging receptacle with gold contacts; separate spring bars.
- Two-piece woven strap with edge stitching, buckle and keeper, following the clay wrist and wrapping the spring bars inside the lug notches.
- Magnetic charging lead with a USB-A plug, shown in the exploded view only.
- Scale context: the shared clay forearm and left hand (`.kit/context_parts.py`, flat pose, forearm length 130 mm), tilted 6 deg so the pod sits level on the back of the wrist.

Render views: `hero` (front right, 30 deg elevation, worn on the wrist), `exploded` (front right, 28 deg) and `detail` (front right, 38 deg, pod and strap without the arm).

### Differences from model.py

1. **Strap path.** `model.py` draws the strap as a 32 mm radius circular loop centred 31.5 mm below the skin. The appearance model follows the elliptical clay wrist (about 67 x 48 mm) and shows a two-piece strap with a buckle, 21.6 mm wide so it clears the 22 mm lugs in the render. Proposed, awaiting Amish. Recommendation: keep the circle in `model.py` for the drawing and mass figures, and use the elliptical path only for renders.
2. **Screw heads above the lid.** `model.py` has no screw heads. The pan heads stand about 0.85 mm above the lid, so the pod reads about 12.9 mm tall at the screws against the 12 mm envelope (the R6 limit is 14 mm, so R6 is still met). Proposed, awaiting Amish. Recommendation: specify countersunk M2 screws at TRL 4 so the lid stays flush, or accept the pan heads and update the envelope note.
3. **Lid marking and grip ribs.** Neither is in `model.py` or the BOM. Proposed, awaiting Amish. Recommendation: keep both as printed-in features (no cost change), with the mark 0.14 mm raised or debossed.
4. **Module detail and charging lead.** Shield, USB-C position, IC placement and the charging lead shape are indicative only and are not taken from a datasheet. Proposed, awaiting Amish. Recommendation: accept as illustration only.

### Confirmation

This is an appearance model only: no tolerances, no fabrication detail, nothing past TRL 3. `trl: 3` is unchanged in `project.yaml`, and TRL 4 remains on hold.

## Session 2026-09-27: kit 1.5.0 and image quality

- Kit 1.5.0 synced: STANDARDS v1.5 (sections 12 to 15: product renders, storefront images and image quality, public release, authorship and signing), `.kit/cards.py`, `.kit/image_qc.py`, `.kit/release_gate.py`, issue templates, and the `/render-product` and `/release` commands. `CLAUDE.md` now matches `.kit/CLAUDE.md`.
- Every `media/render-*.png` recaptioned from its original render with the new layout: the title, concept label and repository sit in a band above the render and the view note in a band below it, each line wrapped to the image width, so no text overlaps other text or the render or runs off the image. `media/card.png` and `media/social-preview.png` regenerated with the same rules.
- `python .kit/image_qc.py` and `python .kit/release_gate.py` pass. trl stays 3.

## Session 2026-10-02: design for construction and the prototype build plan (kit 1.7.0)

Authority: Amish, 2026-09-30, approved the build plan format ("this is the correct build plan ... this is a good quality document format. Extend this across all the other repos"), asked that outstanding decisions go in a separate design decisions register, and wrote: "If you are realising that the design cannot be built as per concept - fix the design assumptions to match and be physically feasible as you draw the illustrations." On 2026-10-01 he set budgets as value-engineering targets. TRL stays at 3; nothing was built, bought or tested.

### What was done

- Kit 1.7.0 installed (`.kit/`, `.claude/commands/`); `CLAUDE.md` matches `.kit/CLAUDE.md`.
- Constructability review of `cad/src/model.py` with build123d intersection and distance checks; the model now carries every part that is made or fitted, and `python cad/src/model.py --check` runs 29 checks, all passing.
- `docs/decisions/0003-design-for-construction.md` (TRT-DDR-003 v0.1, Draft): every change, with its reason.
- `docs/05-build-plan.md` (TRT-BLD-001 v0.1) with `cad/src/build_plan_media.py`: overview, four making sketches (`cad/drawings/TRT-DWG-101` to `104`), five joint close-ups, eight step pictures and a wiring diagram in `docs/05-build-plan/`.
- `docs/06-design-decisions.md` (TRT-DEC-001 v0.1): ten open decisions, eight items to confirm at purchase, a value-engineering section and the decisions made.
- STEP and STL regenerated (`cad/step/`, `cad/stl/`); TRT-DWG-002 Rev P3; concept media and `media/model.glb` regenerated.
- TRT-CAL-001 v0.3, TRT-REQ-001 v0.5, TRT-PRC-001 v0.6, `bom/bom.csv`, `bom/bom-notes.md`, `docs/04-calcs/sizing.py`, `project.yaml` (`design_state: constructable`, new evidence) and `README.md` (links line, "Building the prototype", value-engineering target) updated; PDFs rebuilt.

### Design changes made for construction (TRT-DDR-003)

| # | Change |
| --- | --- |
| C1 | Spring bar holes 1.0 mm through each lug horn for the bar tips (were 1.8 mm, wider than the bar body, so a bar could slide out) |
| C2 | Four M2 x 6 countersunk screws, one in each lug horn, 4 mm of thread in solid plastic (were two on the centre line whose pilot holes broke into the strap notch) |
| C3 | Strap notches 4.5 mm deep (were 4.0 mm; the looped strap rubbed the notch face) |
| C4 | Printed glue collar round the charging receptacle opening; receptacle set in epoxy (had no fixing) |
| C5 | Three printed ribs make a cell pocket with 0.3 mm clearance (the cell was free to slide) |
| C6 | Upper foam pad, 2 mm squeezed to 1.7 mm, so the lid clamps the stack; lower pad modelled (the module floated) |
| C7 | Cell plug cut off and leads soldered to the module's battery pads (the plug had no room) |
| C8 | Light pipe modelled, 2 mm long, set in epoxy flush with the top |
| C9 | Gasket printed 0.8 mm, squeezed to 0.5 mm, with four screw holes |

Knock-on: mass 26.2 g (was 25.4 g), still 3.8 g under the 30 g R6 limit. Value-engineering target: USD 150. Estimated cost of the constructable design: USD 43.69 (USD 106.31 under the target; was USD 43.19). No requirement changed status.

### Proposed, awaiting Amish

- Accept TRT-DDR-003 (register item 1). Recommendation: accept.
- A1 firmware update route once the pod is sealed. Recommendation: over Bluetooth, with opening the pod kept for recovery.
- A2 the skin-side charging contacts. Recommendation: confirm the module's 5 V pin is dead with no charger; add a Schottky diode if it is not.
- Carried over, unchanged: O1 to O3 (partner, OpenRatio, kit 1.3.1) and the 2026-09-26 appearance items 1, 3 and 4. All are in `docs/06-design-decisions.md`.

### Stale files (made on Amish's Mac)

`media/render-hero.png`, `media/render-exploded.png`, `media/render-detail.png`, `media/card.png`, `media/social-preview.png` and the appearance model `cad/src/product_model.py` still show two pan-head lid screws on the centre line; the change to four flush countersunk screws in the lug horns is visible on the lid. They need regenerating with `/render-product` on the Mac. They were not regenerated here.

### Safety concerns

- Unchanged: not a medical device; protected cell, never charged while worn, 50 mA setting; tremor data stays local.
- New: the cell's plug is cut off during the build (safety stop S2: one lead at a time); the charging contacts touch the skin (A2 and safety stop S6).

### Recommended next step

Amish reviews TRT-DDR-003 and the register. TRL 4 (building to TRT-BLD-001 and recording the first checks) remains on hold by his instruction.

## Session 2026-10-02: open decisions decided

Amish, 2026-10-02: "APPROVED: The open decisions from the last wave (TremorTrace to ZeerBox) came in after the review and aren't on the page either." This approves the recommendation written for each open decision in the design decisions register (TRT-DEC-001), as he did for the other 555 open decisions ("i approve your recommendations for all 555 open decisions."). trl stays 3; no build or test work was done, and the model, BOM quantities and prices, and pictures are unchanged.

### Decisions recorded

Ten decisions, all moved to Decisions made in TRT-DEC-001, dated 2026-10-02:

1. Design for construction accepted: the changes C1 to C9 of TRT-DDR-003, as made.
2. Firmware update route: over Bluetooth with the nRF52840's over-the-air bootloader; opening the pod, with a new gasket, is kept for recovery only.
3. Skin-side charging contacts: a small Schottky diode is fitted in the receptacle's positive lead on every band, and the bought module's 5 V pin is still checked dead with the cell connected and no charger; the diode is dropped only if measurements show the pin dead in every operating state.
4. First co-design and validation partner: the first candidate to approach is an academic movement disorders clinic with its own ethics board, introduced through the OpenRatio network, with the International Essential Tremor Foundation as the route to participants, shared with StillBand and SteadySleeve. No prototype is worn without clinical oversight and ethics approval.
5. OpenRatio confirmed as a named possible partner, described in soft, non-clinical wording as a research and educational network, not a clinical service.
6. Kit 1.3.1 approved: concept media for small objects show a forearm for scale instead of the 1.75 m person.
7. Strap path: the circular strap stays in the parametric model for the drawing and mass; the elliptical wrist path is used in renders only.
8. Lid mark and grip ribs kept as printed-in features at no cost, with the mark debossed 0.4 mm (two 0.2 mm layers) into the 1.5 mm lid.
9. Module detail and charging lead in the renders accepted as illustration only.
10. Tremor during a reach: the separate activity flag is kept and tremor is reported both with and without it; a classifier is chosen at TRL 4 from recorded data.

### Documents changed

- `docs/06-design-decisions.md` (TRT-DEC-001 v0.2): open decisions moved to Decisions made; the 2026-09-30 row and confirm item 5 updated.
- `docs/decisions/0003-design-for-construction.md` (TRT-DDR-003 v0.2): acceptance recorded in the status line; A1 and A2 decided (status stays Draft).
- `docs/decisions/0001-trl2-review-decisions.md` (TRT-DDR-001 v0.3) and `docs/decisions/0002-recommendations-accepted.md` (TRT-DDR-002 v0.2): O1 to O3 recorded as decided.
- `docs/02-concept.md` (TRT-PRC-001 v0.7): partner and activity-flag open questions answered.
- `docs/01-problem.md` (TRT-PRB-001 v0.4): partner open question answered.

### Follow-up actions to carry approved decisions into the design

1. Decision 3 (model): Add the Schottky diode in the charging receptacle's positive lead to the model's wiring and the TRT-DDR-003 wiring description, and check it fits beside the module in the cavity.
2. Decision 3 (BOM): Add the Schottky diode (a small SOD-123 or axial part, a few cents) to the BOM and the parts total.
3. Decision 3 (pictures): Redraw the wiring diagram and wiring step of the build plan (TRT-BLD-001) with the diode, and add it to safety stop S3's polarity check.
4. Decision 3 (calculations): Add the diode to the cost in TRT-CAL-001 and the Value engineering section when sizing.py is next run.
5. Decision 8 (model): Model the lid mark as a 0.4 mm deboss in the lid and the grip ribs of the appearance model on the base, then regenerate STEP, STL and drawing TRT-DWG-002.
6. Decisions 1 and 8 (pictures): Update the appearance model and photoreal renders, card and social preview on Amish's Mac: four flush countersunk screws in the lug horns (C2) and the 0.4 mm debossed mark.
7. Decision 2 (docs): State in the firmware sketch notes and the build plan's firmware step that the over-the-air bootloader is loaded before the lid is closed, and that opening the pod is for recovery only.
8. Decisions 4 and 5 (docs): Approach an academic movement disorders clinic through the OpenRatio network, with the International Essential Tremor Foundation for participants, jointly with StillBand and SteadySleeve.

### Points found in the review

- Item 6 (kit 1.3.1) is already applied in practice: the concept media use the forearm and the kit's CLAUDE.md names TremorTrace as the worked example, so the decision only records what is done.
- Item 8's 0.14 mm mark height is below one print layer (0.2 mm); the recommendation restates it as a 0.4 mm deboss.
- The appearance model, photoreal renders, card and social preview still show two pan-head screws on the center line, which change C2 replaced with four flush countersunk screws.

## Session 2026-10-02: approved follow-ups carried out

Amish approved all follow-up actions on 2026-10-02. Done: 6 of 8 in full, 1 in part (scenes exported, photoreal images made on Amish's Mac), 1 not done (outreach). No requirement changed status. trl stays 3. TremorTrace remains a research and educational prototype, not a medical device.

### Follow-ups

1. Decision 3, model: done. A SOD-123 Schottky diode lies on the base floor 8.5 mm to one side of the receptacle opening, 3.2 mm from the receptacle and 3.5 mm or more from the module and cell; the wiring description is in TRT-DDR-003. 38 of 38 constructability checks pass (9 new). STEP and STL regenerated.
2. Decision 3, BOM: done. Line 12, Schottky diode, USD 0.10 (a few cents each in volume, USD 0.10 allowance for a single buy). Parts total USD 43.79.
3. Decision 3, pictures: done. Wiring diagram (Figure 11), steps 1 and 4, safety stop S3 (diode check with the meter) and joint 5 redrawn or reworded; the diode also appears in steps 5, 7 and 8 and the overview.
4. Decision 3, calculations: done. TRT-CAL-001 v0.4 cost: Value-engineering target: USD 150. Estimated cost of the constructable design: USD 43.79 (USD 106.21 under the target). Mass 26.2 g (diode 0.02 g), margin 3.8 g. `budget_usd` unchanged.
5. Decision 8, model: done. The lid mark is a 0.4 mm deboss in the 1.5 mm lid (1.1 mm left under it), clear of the light pipe and screws; grip ribs remain on the base in the appearance model. TRT-DWG-002 Rev P4, TRT-DWG-102 sketch note.
6. Decisions 1 and 8, renders: scenes done, photoreal images, card and social preview not done (made on Amish's Mac). `cad/src/product_model.py` now shows four flush countersunk screws in the lug horns, the debossed mark and the diode. Scenes exported to `/home/claude/renders/tremortrace` (hero, exploded, detail).
7. Decision 2, docs: done in the build plan (step 3 and the wiring picture) and TRT-DDR-003: the over-the-air bootloader is loaded before the lid is closed; opening the pod, with a new gasket, is for recovery only. There are no firmware sketch notes in the repo (`firmware/` is empty under the TRL 3 cap), so none were edited.
8. Decisions 4 and 5, outreach: not done: outreach to a clinic through the OpenRatio network is Amish's action.

### Documents changed

- `bom/bom.csv`, `bom/bom-notes.md`; `cad/src/model.py`, STEP and STL; `cad/src/product_model.py`; `cad/src/sheets.py` (TRT-DWG-002 Rev P4); pictures from `cad/src/build_plan_media.py`
- `docs/04-calcs/sizing.py` and TRT-CAL-001 v0.4; TRT-BLD-001 v0.2; TRT-REQ-001 v0.6 (R10 cost); TRT-DEC-001 v0.3; TRT-PRC-001 v0.8; TRT-DDR-003 v0.3; `README.md`

### Cross-repo actions

- Outreach to an academic movement disorders clinic is shared with StillBand and SteadySleeve (Amish).

## 2026-10-02: photoreal renders redone on the constructable design

Rendered with Blender Cycles on Amish's Mac from the updated appearance model; captioned with `.kit/photo_caption.py`; `media/card.png` and `media/social-preview.png` regenerated with `.kit/cards.py`. Views: hero, exploded, detail. image_qc passes. Appearance deviations are those logged above as proposed, awaiting Amish.

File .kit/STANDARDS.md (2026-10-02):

---
doc_id: OHP-STD-001
title: Documentation and drawing standard
project: Open Hardware Portfolio
doc_type: Standard
version: "1.7"
status: Released
date: 2026-09-30
author: Amish Chadha
license: CC-BY-SA-4.0
revisions:
  - version: "1.0"
    date: 2026-09-24
    author: Amish Chadha
    change: First release of the standard
  - version: "1.1"
    date: 2026-09-24
    author: Amish Chadha
    change: Adopt Technology Readiness Levels (section 9) for project maturity
  - version: "1.2"
    date: 2026-09-24
    author: Amish Chadha
    change: Portfolio phase cap (section 10), concept media standard (section 11), CLAUDE.md guardrails
  - version: "1.3"
    date: 2026-09-24
    author: Amish Chadha
    change: Scale figure, interactive 3D viewer and flow diagrams added to concept media; session slash commands
  - version: "1.4"
    date: 2026-09-26
    author: Amish Chadha
    change: Every sheet and render names the project and its GitHub repository; overall dimensions, ISO centre lines and 300 dpi PNG on sheets; titles name the device and view labels state the viewing direction; optional photoreal renders with Blender
  - version: "1.5"
    date: 2026-09-27
    author: Amish Chadha
    change: Product renders (section 12), storefront images and image quality check (section 13), public release and release gate (section 14), authorship, citation and commit signing (section 15)
  - version: "1.6"
    date: 2026-09-29
    author: Amish Chadha
    change: Licensing metadata with REUSE (section 16), Zenodo DOI and Software Heritage archiving (section 17), release gate checks REUSE and a single CITATION.cff license, archive.py
  - version: "1.7"
    date: 2026-09-30
    author: Amish Chadha
    change: Concept and constructable design states; design decisions register (DEC) kept apart from the build plan; prototype build plan (BLD, section 18) with pictures by component is required TRL 3 evidence; every repo targets TRL 3 during the populate phase; build_views.py; /to-trl3 and /build-plan commands
---

# Documentation and drawing standard

Every project in the portfolio uses this standard, so that each precis, write-up and sketch looks the same and carries its own version history. The standard ships as a kit in each repo's `.kit/` folder. The kit version is in `.kit/KIT_VERSION`.

## 1. Document types and IDs

Every controlled document has a unique ID in the form `PRJ-TYP-NNN`.

- `PRJ` is the three-letter project code listed in section 7.
- `TYP` is the document type code from the table below.
- `NNN` is a sequence number within that project and type, starting at 001.

| Code | Type | Typical file |
| --- | --- | --- |
| PRC | Design precis | `docs/02-concept.md` |
| PRB | Problem statement | `docs/01-problem.md` |
| REQ | Requirements | `docs/03-requirements.md` |
| CAL | Calculation or sizing note | `docs/04-calcs/*.md` |
| DDR | Design decision record | `docs/decisions/*.md` |
| BOM | Bill of materials | `bom/bom.csv` |
| DWG | Drawing or sketch sheet | `cad/drawings/*.svg` |
| BLD | Prototype build plan (section 18) | `docs/05-build-plan.md` |
| DEC | Design decisions register (section 18) | `docs/06-design-decisions.md` |
| TST | Test plan or test report (front matter adds `environment: lab` or `relevant`) | `docs/05-tests/*.md` |

Example: `TBK-PRC-001` is the ThermaBrick design precis.

## 2. Revision scheme

| Artifact | While in draft | When released | Change after release |
| --- | --- | --- | --- |
| Documents | 0.1, 0.2, 0.3 ... | 1.0 | 1.1 for minor edits, 2.0 for a design change |
| Drawings | Rev P1, P2 ... (preliminary) | Rev A | Rev B, C ... |

- Every change to a controlled document adds a row to its revision history before the commit.
- The `version` field in front matter always equals the newest row in `revisions`. The renderer rejects a document where they differ.
- Status is one of `Draft`, `In review`, `Released` or `Superseded`. Draft and In review documents print with a status band on every page.
- Every release is tagged in Git as `<doc_id>/v<version>`, for example `TBK-PRC-001/v1.0`. Drawings are tagged `TBK-DWG-001/revA`.
- Git history is the full audit trail. The in-document revision table is the human-readable summary.

## 3. Document front matter

Every Markdown document under version control starts with this block:

```yaml
---
doc_id: TBK-PRC-001
title: ThermaBrick design precis
project: ThermaBrick
doc_type: Precis
version: "0.1"
status: Draft
date: 2026-09-24
author: Amish Chadha
license: CERN-OHL-S-2.0
revisions:
  - version: "0.1"
    date: 2026-09-24
    author: Amish Chadha
    change: Initial draft
---
```

Quote version numbers so YAML keeps `1.0` as text instead of turning it into a number. List revisions newest last.

## 4. Writing style

- Chicago Manual of Style.
- No em dashes. Restructure the sentence instead.
- Lead each section with its conclusion, then support it.
- SI units throughout, in the form `12 kW`, `450 °C`, `3.2 m`. Imperial values may follow in parentheses.
- Number every figure and table ("Figure 2", "Table 1") and give each a caption.
- State every assumption in the calculation that depends on it.
- Put safety notes in a blockquote starting with **Safety:**.

## 5. Visual identity

| Element | Specification |
| --- | --- |
| Typeface | IBM Plex Sans for text, IBM Plex Mono for code and values (SIL Open Font License, bundled in `.kit/fonts`) |
| Ink | `#111827` |
| Secondary text | `#4B5563` |
| Rules and grid | `#D1D5DB` |
| Accent (one only) | `#0F766E` teal |
| Document page | US Letter, 20 mm margins |
| Drawing sheet | ANSI B landscape (431.8 x 279.4 mm) |
| Footer | Document ID, version, status, license and designmolecule.com on every page |

## 6. Drawing and sketch conventions

- Units are millimeters unless the title block says otherwise.
- Third-angle projection, marked with the symbol in the title block.
- Line weights: visible outlines 0.5 mm, hidden lines 0.25 mm dashed, center lines 0.18 mm chain.
- The title block contains the project, title, drawing number, revision, scale, units, projection, sheet, author, date, material or notes, and license.
- Every sheet and every render names the project and its GitHub repository (from `repo:` in `project.yaml`), at the top of the sheet and in the title block, so a printed or forwarded sheet is never anonymous.
- The drawing title names the device, not only the drawing type (for example "Handheld near-infrared resin scanner: general arrangement").
- Every view label states its scale and viewing direction (for example "Scale 1:1; side elevation looking along +Y"), and every isometric or render states where it is seen from.
- Orthographic views generated with `add_ortho` carry overall dimensions (length and depth on the top view, height on the front view) and ISO 128 centre lines on cylinders; hidden lines are dashed. Tolerances are not shown before TRL 4.
- Sheets are exported as SVG, PDF and a 300 dpi PNG.
- The revision table in the top right of the sheet lists every revision.
- Concept sketches use the same sheet and title block and carry the label "CONCEPT, NOT FOR FABRICATION".
- Geometry comes from `cad/src/*.py` (build123d). Sheets are generated by `.kit/drawing.py` and never edited by hand.

## 7. Project codes

| Code | Project | Code | Project | Code | Project |
| --- | --- | --- | --- | --- | --- |
| TBK | ThermaBrick | PCF | PicoFlow | HLT | HelioLite |
| CCB | CharCube | DRN | DustRunner | TRT | TremorTrace |
| STC | StepCue | FXH | FlexHand | CPD | ColdPod |
| SCL | SunClave | STR | SteamRoot | GGD | GrainGuard |
| SDL | SeedLine | ZBX | ZeerBox | RMS | RootMesh |
| DWD | DewDrive | SSK | StillStack | PPR | PotPress |
| WWT | WaterWatch | LMF | LumaFlow | FCL | FieldCell |
| CNP | ConePro | CVC | CulvertCrawl | EGD | EmberGuard |
| SNF | SnapFrame | CGM | CargoMule | SCM | StepClimber |
| SWC | SwapCell | PLP | PalletPilot | FTK | FlatTrike |
| WWK | WaterWalker | GRR | GrowRider | SSP | SunSpoke |
| SGN | StepGen | PBX | PowerBox | WML | WasteWise-ml |
| WSC | WasteWise Scan | RFE | ReflowEconomy | | |
| OHP | Portfolio-wide | | | | |

## 8. Build and publish

- `python .kit/render.py` checks every controlled document and renders it to `docs/pdf/<doc_id>_v<version>.pdf`.
- `python .kit/drawing.py` (called from each project's `cad/src/sheets.py`) builds drawing sheets as SVG and PDF in `cad/drawings/`.
- The GitHub Action in `.github/workflows/docs.yml` runs the checks on every push and attaches PDFs to a GitHub Release whenever a release tag is pushed.
- Public releases follow section 14: `python .kit/release_gate.py` must pass, and the release tag is `v0.<TRL>.0` (for example `v0.3.0` at TRL 3).

## 9. Technology Readiness Level (TRL)

Each project states its maturity as a Technology Readiness Level on the NASA and US DOE 1 to 9 scale. The TRL rates this specific design, not the underlying technology. A sand battery is commercial elsewhere, but a new sand battery design starts at TRL 2 until evidence shows otherwise.

| TRL | Definition | Evidence the repo must contain |
| --- | --- | --- |
| 1 | Basic principles observed | Problem statement (PRB) |
| 2 | Technology concept formulated | Draft precis (PRC) and requirements (REQ) |
| 3 | Analytical or experimental proof of concept | Calculation note (CAL), working build123d model with STEP export, drawing sheet (DWG), priced BOM with every unit cost filled in, prototype build plan (BLD) with pictures, `design_state: constructable` |
| 4 | Components validated in the lab | Test report (TST) with `environment: lab`, build log entries |
| 5 | Validated in a relevant environment | Test report (TST) with `environment: relevant` |
| 6 | System prototype demonstrated in a relevant environment | Precis at version 1.0 or later with status Released, a drawing at a lettered revision (Rev A or later), and a system-level TST with `environment: relevant` |
| 7 to 9 | Operational demonstration through proven in service | Beyond portfolio scope; claim only with a named deployment partner and evidence |

Rules:

- `project.yaml` records `trl` (current level), `trl_target` (the level the current effort aims for) and `trl_evidence` (the files that support the claim).
- `python .kit/render.py --check` fails if the evidence for the claimed TRL is missing. CI runs this check on every push.
- Documentation alone cannot go past TRL 3. TRL 4 and above require hardware and a test report.
- TRL and visibility are independent. A repo can be public at TRL 3 as a documented design ready to build.
- A change of TRL is recorded in the build log with the date and the evidence that justified it.

## 10. Portfolio phase and TRL cap

`.kit/PHASE.yaml` sets the current phase. During the **populate** phase every repo is capped at **TRL 3**: `trl` and `trl_target` may not exceed 3, and the check fails if they do. Every repo targets the cap: `trl_target` must equal 3, so a new repo is taken all the way to TRL 3 (scaffold, populate and advance, see `/to-trl3`). Work that belongs to TRL 4 or later (building or testing hardware, test articles, test plans and reports, build-log entries, purchasing lists, PCB layouts) must not be started. The prototype build plan (BLD, section 18) is TRL 3 paper work and is required. Where it already exists it is kept, flagged in the check output, and not extended. Only Amish changes `PHASE.yaml`.

Every repo carries a `CLAUDE.md` with the working rules for AI sessions: the TRL cap, decision rights (nothing is recorded as decided unless Amish decided it), one step per session, and a mandatory `docs/REVIEW.md` before stopping.

## 11. Concept media

Every repo at TRL 2 or above explains its idea visually. Media are generated from a build123d massing model with `.kit/concept.py`, never drawn by hand, so they stay in step with the design.

| File | Required | Purpose |
| --- | --- | --- |
| `media/hero.png` | TRL 2+ | Shaded isometric render with a 1.75 m person for scale; the website card image |
| `media/concept-blueprint.png` and `.pdf` | TRL 2+ | Blueprint concept sheet: orthographic and isometric views, scale, key figures, title block |
| `media/model.glb` and `media/viewer.html` | TRL 2+ | Interactive 3D viewer (glTF plus model-viewer) for the website |
| `media/cutaway.png` | When the inside matters | Section view showing internal parts |
| `media/exploded.png` | Recommended | Exploded view with numbered callouts matching the BOM |
| `media/flow.png` | When energy or material moves | System, energy or material flow diagram with losses |

Session commands in `.claude/commands/` (`/populate`, `/advance-trl3`, `/rein-in`, `/refresh-media`) carry the standard prompts, so every Claude Code session starts from the same instructions.

At TRL 2 a massing model is enough: correct overall proportions and main components. All concept media carry "CONCEPT, NOT FOR FABRICATION". The check warns when required media are missing at TRL 2 and fails at TRL 3.

## 12. Product renders

Every repo at TRL 3 shows the product as it would look, not only as a massing model.

- `cad/src/product_model.py` is the appearance model. It defines `product_parts()` (named parts with a shape and a material), `TITLE` ("Name: what it is") and `RENDER_VIEWS`. It is for renders only: every main dimension comes from `cad/src/model.py`, never typed in again.
- Where the appearance model departs from `model.py` (a chamfer, a label, a fastener drawn for realism), record the deviation in `docs/REVIEW.md` as "Proposed, awaiting Amish".
- Scale comes from context, not from a floating figure: a hand or forearm for handheld objects, and the posed mannequin (`mannequin()` in `.kit/context_parts.py`: stand, walk, push, ride, sit, reach) for anything a person uses at body scale.
- Renders are made with `.kit/export_views.py` (one scene per view) and `.kit/photoreal.py` (Blender Cycles), then captioned with `.kit/photo_caption.py`. Files are `media/render-<view>.png`; `media/render-hero.png` is required.
- Every caption names the project, the repository and the viewing direction, and carries "CONCEPT, NOT FOR FABRICATION".
- Captions never sit on the render. `.kit/photo_caption.py` adds a header band (title, concept label, repository) above the render and a footer band (view note) below it, wraps every line to the image width, and steps the font down to a floor before adding a line.
- The README opens with `media/render-hero.png`.
- Software-only and scene repositories (no single product) may use a scene render as the hero instead of a product model.

## 13. Storefront images

Two images, both made from `media/render-hero.png` by `python .kit/cards.py .`:

| File | Size | Purpose |
| --- | --- | --- |
| `media/card.png` | 800 x 800 | Square thumbnail for the organization profile page |
| `media/social-preview.png` | 1280 x 640, under 1 MB | GitHub social preview, shown when a repository link is shared |

- The social preview shows the area, name, one-line description, the first sentence of the pitch, the brand line and the repository address. Design Molecule repos read "Design Molecule · open hardware concept, TRL n"; OpenRatio repos read "OpenRatio · research and educational prototype, TRL n".
- GitHub has no API for the social preview. Upload it under the repository's Settings, Social preview, on release day.
- Regenerate both images whenever `render-hero.png` changes.

### Image quality

Every render, card and social preview must be clear and readable. `python .kit/image_qc.py` checks each one, and the release gate blocks on any failure:

| Check | Rule |
| --- | --- |
| Layout | Made by the current `photo_caption.py` or `cards.py`, which store the text layout in the PNG |
| Text inside the image | Every line at least 1.2 % of the image width from each edge; nothing runs off the side |
| No overlap | No line of text touches another line, and no caption text sits on the render |
| Text size | Render captions at least 1.05 % of the image width in pixel height (17 px at 1600 px); social preview text at least 16 px |
| Resolution | Renders at least 1200 px wide; card 800 x 800; social preview 1280 x 640 and under 1 MB |
| Sharpness | The render is not blurred or upscaled (edge sharpness at least 15 on the `image_qc.py` scale) |

Long titles and notes wrap to more lines rather than shrinking below the floor. The social preview shortens the pitch sentence with an ellipsis only if it cannot fit at the smallest size.

## 14. Public release

A repository goes public only when Amish approves it, and only after `python .kit/release_gate.py` passes. The gate checks:

1. `render.py --check` passes (document control, TRL cap, concept media).
2. Storefront: hero render, card, social preview under 1 MB, README leading with the hero, and every image passing the image quality check (section 13).
3. Issue templates in `.github/ISSUE_TEMPLATE/`: question, build report, design suggestion. The build report template restates that the design is a TRL 3 concept, not released for fabrication (OpenRatio: a research and educational prototype, not a medical device).
4. `CITATION.cff` valid, with an author ORCID.
5. License files match `project.yaml`.
6. No em dashes in the repository's own text.
7. BioMedical and OpenRatio repos use soft, non-clinical wording: "research and educational prototype, not a medical device".
8. No secrets anywhere in the history (gitleaks).
9. No links to sibling repositories that are still private.
10. REUSE files present (`REUSE.toml`, `LICENSES/`, `.github/workflows/reuse.yml`) and `reuse lint` passes (section 16).
11. `CITATION.cff` names exactly one license, because Zenodo rejects a list (section 17).

It warns, without blocking, when the README lacks a Safety heading or a "not for fabrication" statement, when `CITATION.cff` has no DOI yet, and when the README lacks the Zenodo DOI, REUSE or Software Heritage badge, so a person can confirm.

On release day, per repository:

- A signed, annotated tag `v0.<TRL>.0` on `main`.
- A GitHub release with short notes (what it is, TRL, status, licenses, how to cite) and a design pack, `<repo>-v0.<TRL>.0-design-pack.zip`, holding `cad/step`, `cad/drawings`, `docs/pdf`, `bom`, README, licenses and `CITATION.cff`.
- Description from the first sentences of `pitch` (350 characters at most), website `https://designmolecule.com` (OpenRatio: `https://openratio.ai`), topics from `project.yaml`.
- Before the first release, the repository is switched on in Zenodo (section 17), so the release is archived and gets a DOI.
- Visibility switched to public last, after the release exists.
- The social preview uploaded and the organization profile updated with the new cards.
- After the release: the concept DOI written to `CITATION.cff` and a Software Heritage save requested (section 17).

The internal working files (`CLAUDE.md`, `.kit/CLAUDE.md`, `.claude/commands/`, `docs/REVIEW.md`) stay public, and open "Proposed, awaiting Amish" items stay visible as open questions (Amish, 2026-09-27).

## 15. Authorship, citation and signing

- Amish Chadha is the author of every design, ORCID 0009-0000-8079-7141. Commits are authored as Amish Chadha <amish@designmolecule.com>.
- `CITATION.cff` lists Amish (with ORCID) first, then any credited contributors; `CONTRIBUTORS.md` and the README Credits section agree with it.
- `CITATION.cff` names one license: the hardware license (CERN-OHL-S-2.0), or the software license in a software-only repository. The full split between hardware and software licenses lives in `REUSE.toml` and the README. Once the repository is archived, `CITATION.cff` carries the concept DOI in `doi:`.
- Work done with Claude carries the trailer `Co-Authored-By: Claude <noreply@anthropic.com>` (with the model name), and the README Credits section says designs are developed with AI assistance.
- Every commit and tag pushed to GitHub is signed with Amish's SSH signing key, so GitHub shows it as Verified. Commits prepared elsewhere are re-signed on Amish's Mac before they are pushed.
- Once a repository is public, its history is never rewritten.

## 16. Licensing metadata (REUSE)

Every file states its copyright and license in a machine-readable way, following the REUSE Specification 3.3 (https://reuse.software). A repository is set up with:

```
python .kit/archive.py reuse
```

This writes three things and adds the REUSE and Software Heritage badges to the README badge line:

- `REUSE.toml`, built from the licenses in `project.yaml`. Everything is under the hardware license by default. Scripts, firmware, notebooks, web viewers, workflows and agent commands are under the software license. `cad/` and `electronics/` stay under the hardware license even where they are written as Python. The bundled IBM Plex fonts are OFL-1.1 (IBM Corp.). Copyright is "<first commit year> Amish Chadha".
- `LICENSES/`, with the full text of each license used (`reuse download`). The root `LICENSE` and `LICENSE-SOFTWARE` files stay for GitHub's license detection.
- `.github/workflows/reuse.yml`, which runs the REUSE check (fsfe/reuse-action) on every push and drives the README badge.

A new kind of file that falls outside these rules gets a new annotation in `REUSE.toml` rather than a header comment. `reuse lint` must pass before every commit that adds files, and the release gate enforces it.

## 17. Archiving and DOI (Zenodo and Software Heritage)

Every public repository is archived twice, so the design stays citable and retrievable if GitHub changes.

Zenodo (a citable DOI for each release):

1. Amish's Zenodo account is linked to GitHub. Before the first release, Amish switches the repository on in Zenodo (Account, GitHub). Only Amish changes Zenodo or GitHub settings.
2. Run `python .kit/archive.py zenodo`: it makes sure `CITATION.cff` names one license and adds the Zenodo DOI badge, which uses the GitHub repository ID and always points at the latest version. Zenodo reads its metadata (title, authors with ORCID, license, keywords) from `CITATION.cff`, and rejects the whole archive when that file lists several licenses.
3. Publish the GitHub release (section 14). Zenodo archives it within minutes and mints two DOIs: a version DOI for that release and a concept DOI that stands for all versions.
4. Check the Zenodo record: title, author and ORCID, license, keywords. If Zenodo shows "Citation metadata load failed", fix `CITATION.cff`, validate it with cffconvert and publish a new patch release (for example `v0.3.2`); a failed release is never re-used.
5. Run `python .kit/archive.py zenodo --doi <concept DOI>` and commit, so GitHub's "Cite this repository" and every future archive carry the concept DOI. Every later release gets its own version DOI automatically; the concept DOI never changes.

Software Heritage (permanent source archive):

1. After the repository is public, request a save at https://archive.softwareheritage.org/save/ (origin type git, the repository URL). Anonymous requests are limited to about ten an hour, so batches are spread out.
2. The Software Heritage badge on the README resolves once the save is accepted and ingested. Later pushes are picked up by its regular crawl.

OpenRatio repositories follow the same steps when Amish approves their release.

## 18. Prototype build plan (BLD) and the constructable design

### Two design states

A design moves through two states, recorded as `design_state` in `project.yaml`:

- **Concept**: the design shows what the product does and that it works on paper (TRL 2 and the calculations of TRL 3). Parts may be simplified shapes that have never been checked for how they are made or how they join.
- **Constructable**: every part can be made with the stated process and material, and every part fits and fastens to the parts next to it. Nothing is left as a shape that cannot be cut, cast, bent, printed, machined or bought.

A repo reaches TRL 3 only when its design is constructable and its build plan shows how. Writing the build plan is how the design is made constructable: when a part cannot be made or cannot fit as modelled, change the model so it can (Amish, 2026-09-30: "fix the design assumptions to match and be physically feasible"), keep what the concept does, and record every change in a decision record "Design for construction" (DDR) and in the plan. Changes that alter what the product does, its pitch or its safety case are proposed, not made.

### What the build plan is

`docs/05-build-plan.md` (`PRJ-BLD-001`) tells a capable maker how to build the first proof-of-concept prototype, in order, component by component, and shows it in pictures. It is written before anything is built, states "Plan, not yet built" under the title and never claims results. Building and testing to it is TRL 4 work.

### Writing rules

- **Plain English.** Say "the steel plate the jack stands on", not a model parameter or variable name. No code identifiers, function names, parameter names or file paths in the body of the plan. Give sizes as numbers with units ("a 62 mm hole, centred 100 mm up from the bottom edge"). The only place file names appear is the closing "Where the numbers come from" list.
- **Pictures first.** Every component and every assembly step has a picture. A reader should be able to build from the pictures, with the words explaining what the pictures cannot show (order, force, tolerance, checks).
- **By component, in build order.** Each component is made and checked before the step that needs it.
- **Cost is not the focus.** One line in the overview may state the parts cost from the BOM; there is no cost or time section.

### Sections, in order

1. **What you are building**: the overview picture (every component pulled apart and numbered in build order) and one short paragraph.
2. **What changed to make it buildable**: a table of each change from the concept (what the concept had, what the constructable design has, why), with a picture where the change is visible. "None" if nothing changed.
3. **Making the components**: one subsection per made component, in build order, each with:
   - its making sketch (three views with overall sizes, a 3D view, where it goes, making notes), `cad/drawings/PRJ-DWG-1NN`;
   - what it is and what it is made from (material, stock size);
   - how to make it, as numbered steps (mark out, cut, drill, bend, weld, cast, print, machine, finish), with the sizes that matter;
   - how it fits the parts next to it: a close-up picture of the joint, which faces touch, what holds them (bolt, weld, pin, clip, glue), the gap or fit needed, and which side goes where;
   - the check before moving on.
   Bought components get a short subsection: what to buy (specification, not brand), and what to do to it (drill, trim, fit).
4. **Putting it together**: numbered assembly steps, each with a step picture (parts already fitted in grey, the part being fitted in colour with an arrow showing the way it goes in), the fasteners, and any hold point.
5. **First checks**: fit, movement, first power or first load, each tied to a requirement ID with a pass criterion. The plan lists them; a TRL 4 test report records them.
6. **Safety stops**: points where work stops (before energising, pressurising, loading, lifting or operating) and what must be true to carry on.
7. **Tools, skills and workspace.**
8. **Where the numbers come from**: the model, drawings, calculation note and BOM, by file name.

### Budgets are value-engineering targets

`budget_usd` in `project.yaml` is a hypothetical control target that keeps the design thinking along a value-engineering lens; it is not a spending limit (Amish, 2026-10-01: "the budgets are a hypothethical control target to ensure we are thinking along a value engineering lens. its ok to ensure wording reflects that the hypothesis budget was x - the real cost being accrued is y"). Write it that way everywhere: "Value-engineering target: USD X. Estimated cost of the constructable design: USD Y (USD Z over or under the target)." A cost requirement is reported against the target ("over the value-engineering target by USD Z"), never as a failure that needs a budget decision, and the design decisions register does not carry "raise the budget" decisions. Instead the register has a short **Value engineering** section: target, estimated cost, the main cost drivers and the savings worth trying.

### Decisions live in their own document

The build plan describes the design as it stands; it never lists outstanding decisions, open questions or items awaiting Amish (Amish, 2026-09-30: "don't log outstanding decisions in this build plan - that is not the place for it. that should be in a separate design document logged and named as such"). Those go in the **design decisions register**, `docs/06-design-decisions.md` (`PRJ-DEC-001`), which has two tables: open decisions (what is to be decided, options, recommendation, what it affects in the build, source record) and decisions made (date, decision, Amish's words where recorded, link to the decision record). Things to confirm when parts are bought (for example a panel's frame lip) are open items in the register too. The build plan may say "see the design decisions register" once, in its introduction.

### Pictures

Pictures are generated from the model by `cad/src/build_plan_media.py` using `.kit/build_views.py` (overview, component making sketches, joint close-ups, assembly steps), so they always match the model. They are written to `docs/05-build-plan/` and `cad/drawings/`. Look at every picture before committing: labels readable, nothing overlapping, the part in question clearly visible.

`render.py --check` at TRL 3 requires a BLD document, `design_state: constructable` in `project.yaml`, and `docs/05-build-plan/overview.png`.

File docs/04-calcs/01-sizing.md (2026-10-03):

---
doc_id: TRT-CAL-001
title: TremorTrace sizing calculations
project: TremorTrace
doc_type: Calculation note
version: "0.4"
status: Draft
date: '2026-10-02'
author: Amish Chadha
license: CERN-OHL-S-2.0
revisions:
- version: "0.1"
  date: '2026-09-25'
  author: Amish Chadha
  change: First-principles sizing for TRL 3 against TRT-REQ-001 v0.3
- version: "0.2"
  date: '2026-09-25'
  author: Amish Chadha
  change: Recommendations accepted by Amish (DDR-002)
- version: "0.3"
  date: '2026-10-02'
  author: Amish Chadha
  change: 'Design for construction (TRT-DDR-003): mass 26.2 g, cost USD 43.69; budget treated as a value-engineering target'
- version: "0.4"
  date: '2026-10-02'
  author: Amish Chadha
  change: 'Schottky diode added to the cost (USD 43.79 over 12 lines) and the mass; no requirement status changed'
---

# TremorTrace sizing calculations

The design meets nine of the eleven requirements in TRT-REQ-001 by calculation or design review and two cannot be verified at TRL 3 (R7 splash resistance and R8 daily profile notebook). R6 mass, at risk in v0.1 at 29.4 g, is met at 26.2 g with the textile strap adopted in TRT-DDR-002 and the parts added to make the design buildable (TRT-DDR-003). No requirement is shown to be not met. Two conditions carry the result: the firmware must measure the IMU's true sample rate against the module's crystal (R1), and it must sleep between samples (R4).

Every number in this note is printed by `docs/04-calcs/sizing.py` (run `python docs/04-calcs/sizing.py` from the repo root). Size and mass read the geometry directly from `cad/src/model.py`; cost reads `bom/bom.csv`.

> **Safety:** TremorTrace is a research and educational prototype, not a medical device. It carries a lithium polymer cell against the skin: use a protected cell, never charge while worn, and stop use if the pod becomes warm or swollen.

## 1. Results against requirements

Table 1 lists every requirement. Status is one of met, not met, at risk, or not verifiable at TRL 3.

Table 1. Requirement status at TRL 3.

| ID | Target | Value from this note | Status |
| --- | --- | --- | --- |
| R7 | Silicone or textile strap, no exposed electronics, IP54 target | Sealed PETG pod with TPU gasket, contacts through the floor; no ingress test possible on paper | Not verifiable at TRL 3 |
| R8 | Open notebook producing a daily profile | Summary record defined (Table 4); notebook not yet written | Not verifiable at TRL 3 |
| R1 | 3 to 15 Hz band, resolution 0.2 Hz or better | 0.100 Hz bins, 52 Hz Nyquist; synthetic worst error 0.002 Hz | Met, if the sample rate is corrected against the crystal |
| R6 | Mass 30 g or less with strap; pod within 45 x 35 x 14 mm | 26.2 g (3.8 g margin, textile strap mass assumed 8 g); pod 40 x 30 x 12 mm | Met |
| R2 | Acceleration and angular velocity RMS in band, per window | Noise floor 0.31 mg and 0.017 dps RMS in band; ranges +/-8 g and +/-2000 dps; synthetic amplitude error 0.6 % or less | Met |
| R3 | 6-axis IMU at 100 Hz or more | LSM6DS3TR-C at 104 Hz | Met |
| R4 | 3 days or more at 16 h of wear per day | 6.3 days nominal, 4.5 days conservative | Met, if the firmware sleeps (0.69 days if it never sleeps) |
| R5 | 7 days of summaries at 16 h per day, with raw snippet reserve | 9.7 days after a 256 kB raw reserve | Met (6.4 days if the band logs 24 h per day) |
| R9 | Local storage, owner-controlled export, no cloud | Architecture has no cloud path; web Bluetooth page reads locally | Met (design review) |
| R10 | Parts cost against the USD 150 value-engineering target, no custom PCB | USD 43.79 over 12 BOM lines, USD 106.21 under the target; module plus hand wiring | Met |
| R11 | LED and web Bluetooth page show battery, recording and sync state | RGB LED on the module under a 2 mm light pipe; page defined in TRT-PRC-001 | Met (design review) |

## 2. Sampling and frequency resolution (R1, R3)

Assumptions: the IMU runs at an output data rate of 104 Hz; each summary covers a 10 s window; the tremor band is 3 to 15 Hz.

- Samples per window N = 104 x 10 = 1,040. Bin spacing is 104 / 1,040 = 0.100 Hz, half the 0.2 Hz target. The Nyquist limit is 52 Hz, more than three times the top of the band. The band spans 120 bins.
- The IMU's own oscillator sets the sample rate. Its tolerance is not in the figures used here; this note assumes up to 2 % (to be confirmed). Left uncorrected, 2 % gives up to 0.30 Hz error at 15 Hz, which would miss R1. If the firmware counts samples against the nRF52840's 32.768 kHz crystal (20 ppm), the error falls to 0.30 mHz. R1 is therefore met on the condition that the firmware applies this correction.

A synthetic check ran the window algorithm (mean removal, Hann window, FFT, parabolic peak interpolation, band-limited RMS) on six off-bin tremor frequencies from 3.33 to 14.61 Hz at 0.05 m/s² RMS with the datasheet accelerometer noise added. The worst frequency error was 0.002 Hz and the worst amplitude error was 0.6 %. This checks the arithmetic of the method, not real tremor, which drifts in frequency and amplitude within a window.

## 3. Amplitude noise floor and range (R2)

Assumptions: accelerometer noise density 90 µg/√Hz and gyroscope rate noise density 5 mdps/√Hz (LSM6DS3TR-C datasheet, high-performance mode); a detection floor at three times the in-band noise.

- In a 12 Hz band the accelerometer noise is 90 µg x √12 = 0.31 mg RMS and the gyroscope noise is 0.017 dps RMS.
- The detection floor is 0.94 mg RMS, about 9.3 µm RMS of wrist displacement at 5 Hz. Clinically visible tremor is in the millimeter range, so the floor is not a constraint.
- Range sets the upper limit. A severe tremor of 5 mm peak at 12 Hz is 2.90 g peak; with gravity the sensor sees 3.90 g, too close to a +/-4 g range. The design uses +/-8 g (0.244 mg per LSB). Rotation of +/-20 degrees at 8 Hz is 1,005 dps peak, so the gyroscope uses +/-2000 dps (70 mdps per LSB).

## 4. Activity flag (supporting analysis)

The concept flags a window as voluntary activity when the power below 3 Hz exceeds the power in the tremor band. Four synthetic cases (Table 2) show that the ratio separates rest tremor from a slow reach and from walking with heel strikes, but it also marks tremor during a reach as activity. That would undercount action and postural tremor, the main form in essential tremor.

Table 2. Band-to-low-frequency power ratio in synthetic 10 s windows (flag threshold 1.0).

| Case | Ratio | Flag |
| --- | --- | --- |
| Rest tremor, 5 Hz, 0.3 m/s² | 40,156 | Tremor |
| Voluntary reach, 0.8 Hz, 1.5 m/s² | 0.00 | Activity |
| Walking arm swing plus heel strikes | 0.24 | Activity |
| Tremor at 5 Hz during a reach | 0.04 | Activity |

Consequence for the design: every summary record keeps the tremor-band RMS and dominant frequency whatever the flag says, and the flag is stored as a separate field. The notebook can then report tremor at rest and tremor during activity separately rather than discarding windows. A better classifier is an open question for later work; it cannot be validated on paper.

## 5. Power budget (R4)

Assumptions (Table 3): 16 h per day worn and recording, 8 h off the wrist with the accelerometer in a low-rate wear-detection mode; a 150 mAh protected cell with 85 % usable above a 3.5 V firmware cutoff and a further 90 % for ageing and cold, giving 115 mAh usable.

The MCU duty is estimated from first principles for each 10 s window: reading 1,040 six-axis samples (12,480 bytes) over I²C at 400 kHz takes 281 ms if the CPU waits on the bus; filtering and six 1,024-point FFTs take about 16 ms at 64 MHz; ten FIFO wake-ups take 5 ms. That is a 3.02 % duty, or 0.195 mA average at an assumed 6.3 mA run current plus the module's standby current of less than 5 µA (Seeed wiki).

Table 3. Recording current, mA.

| Load | Nominal | Conservative | Basis |
| --- | --- | --- | --- |
| IMU, accelerometer and gyroscope | 0.90 | 0.90 | ST figure for combined high-performance mode |
| MCU | 0.195 | 0.50 | Duty estimate above; conservative allows untuned firmware |
| BLE advertising, 1 s interval | 0.015 | 0.10 | Assumed |
| QSPI flash writes | 0.005 | 0.02 | Assumed |
| Status LED | 0.002 | 0.01 | 2 mA blink, 10 ms every 10 s |
| Cell protection circuit | 0.003 | 0.005 | Assumed |
| **Total recording** | **1.120** | **1.535** | |
| Off-wrist | 0.050 | 0.080 | Assumed |

Daily use is 18.4 mAh nominal and 25.2 mAh conservative (including a daily sync of 184 kB at an assumed 10 kB/s and 5 mA), so one charge lasts 6.3 days nominal and 4.5 days conservative. R4 is met in both cases. Firmware that never lets the CPU sleep draws 166 mAh per day and lasts 0.69 days, which fails R4; sleep discipline is a firmware requirement, not an option.

Charging: the module's BQ25101 charger has 50 mA and 100 mA settings. At 50 mA the cell charges at 0.33 C in about 3.6 h, and the linear charger dissipates about 65 mW. At 100 mA it charges at 0.67 C in about 1.8 h and dissipates about 130 mW. Both are under the cell's 150 mA limit. This note uses the 50 mA setting to keep the pod cool; decided by Amish, 2026-09-25 (TRT-DDR-002). The firmware must select the 50 mA setting.

## 6. Storage (R5)

Table 4 defines the 32-byte summary record.

Table 4. Summary record, one per 10 s window.

| Field | Bytes |
| --- | --- |
| Timestamp, s | 4 |
| Dominant frequency, 0.01 Hz steps | 2 |
| Tremor-band acceleration RMS and angular velocity RMS | 4 |
| Total acceleration RMS and angular velocity RMS | 4 |
| Band-to-low-frequency power ratio and peak width | 4 |
| Dominant tremor axis, three signed components | 6 |
| Flags (worn, activity, charging) and battery level | 2 |
| Reserved | 4 |
| CRC | 2 |
| **Total** | **32** |

Assumptions: 16 h of wear per day, with no records while off the wrist (a wear-state marker only); the module's 2 MB QSPI flash holds data only, since the firmware lives in the nRF52840's internal flash; 256 kB reserved for on-demand raw snippets; 3 % overhead for sector headers and wear leveling.

- 5,760 records per day x 32 bytes = 184.3 kB per day.
- 1,780 kB is available, which holds 9.7 days at 16 h per day. If wear detection failed and the band logged all 24 h, the history would fall to 6.4 days, under the 7-day target.
- A raw 10 s window is 12,480 bytes, so a summary is 390 times smaller. (The TRL 2 precis said about 1,000 times; corrected in TRT-PRC-001 v0.4.) The raw reserve holds 21 snippets.

## 7. Size and mass (R6)

The pod in `cad/src/model.py` is 40 mm across the wrist, 30 mm along it and 12 mm high, inside the 45 x 35 x 14 mm limit. The internal stack (3.8 mm cell, 0.5 mm foam, 3.5 mm module) is 7.8 mm in a 9.5 mm cavity. The remaining 1.7 mm is filled by an upper foam pad cut from 2 mm foam, so the lid clamps the stack (TRT-DDR-003); wires run down the 1.3 mm gaps beside the cell.

Table 5. Mass estimate.

| Part | Mass, g | Basis |
| --- | --- | --- |
| Enclosure base, PETG | 4.85 | Model volume at 1.27 g/cm³ (ribs, collar and deeper notches added, TRT-DDR-003) |
| Enclosure lid, PETG | 2.22 | Model volume at 1.27 g/cm³ |
| Gasket, TPU | 0.24 | Model volume at 1.21 g/cm³ |
| Textile strap, 22 mm | 8.00 | Assumed |
| Controller and IMU module | 3.00 | Assumed |
| LiPo cell, 150 mAh | 4.65 | Adafruit 1317 listing |
| Charging connector receptacle | 1.00 | Assumed |
| Spring bars, 2 | 0.60 | Assumed |
| M2 x 6 countersunk screws, 4 | 0.60 | Assumed |
| Wire, two foam pads, light pipe, epoxy | 1.00 | Assumed |
| **Total** | **26.2** | |

The total is 3.8 g under the limit, so R6 is met. The strap is still the largest and least certain item: v0.1 of this note used a 12 g silicone strap, which gave 29.4 g and only 0.6 g of margin, so TRT-DDR-002 replaced it with a woven textile strap of about 8 g. A heavier 10 g textile strap would still give 28.2 g. The first TRL 2 estimate (22 g) assumed a 5 g enclosure and a 10 g strap; the model shows the enclosure at 7.3 g. Making the design buildable (TRT-DDR-003) added 0.8 g: two more screws, the upper foam pad, epoxy, and the ribs and collar in the base.

## 8. Cost (R10)

Value-engineering target: USD 150 (`budget_usd`, a hypothetical control target, not a limit). Estimated cost of the constructable design: USD 43.79 (USD 106.21 under the target), over 12 priced lines in `bom/bom.csv`. The Schottky diode in the charging receptacle's positive lead (TRT-DDR-003 A2) adds USD 0.10 and 0.02 g. The textile strap is priced at USD 10.00 against USD 8.00 for the silicone strap in v0.1, and two more lid screws added USD 0.50 under TRT-DDR-003. The cell price and size were checked against the Adafruit listing on 2026-09-25; the other prices are indicative and are confirmed at order.

## 9. Sources

- STMicroelectronics, [LSM6DS3TR-C product page](https://www.st.com/en/mems-and-sensors/lsm6ds3tr-c.html) and [datasheet](https://www.st.com/resource/en/datasheet/lsm6ds3tr-c.pdf): 0.90 mA combined high-performance current, 90 µg/√Hz, 5 mdps/√Hz, full-scale ranges and sensitivities.
- Seeed Studio, [XIAO nRF52840 Series wiki](https://wiki.seeedstudio.com/XIAO_BLE/): 21 x 17.8 mm, 2 MB flash, LSM6DS3TR-C, BQ25101 charger at 50 or 100 mA, standby under 5 µA.
- Adafruit, [Lithium Ion Polymer Battery 3.7 V 150 mAh, product 1317](https://www.adafruit.com/product/1317): 19.75 x 26.02 x 3.8 mm, 4.65 g, protection circuit, charge at 150 mA or less, $5.95.

Values marked "assumed" in this note have no source and are to be confirmed when hardware work is authorized.

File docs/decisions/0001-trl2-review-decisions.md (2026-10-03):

---
doc_id: TRT-DDR-001
title: TremorTrace TRL 2 review decisions
project: TremorTrace
doc_type: Design decision record
version: "0.3"
status: Draft
date: '2026-10-02'
author: Amish Chadha
license: CERN-OHL-S-2.0
revisions:
- version: "0.1"
  date: '2026-09-25'
  author: Amish Chadha
  change: Record Amish's 2026-09-25 decisions on the TRL 2 review points
- version: "0.2"
  date: '2026-09-25'
  author: Amish Chadha
  change: Recommendations accepted by Amish (DDR-002)
- version: "0.3"
  date: '2026-10-02'
  author: Amish Chadha
  change: O1 to O3 recorded as decided by Amish on 2026-10-02
---

# 0001: TRL 2 review decisions

- **Date:** 2026-09-25
- **Status:** accepted (items D1 to D5, and O4 through TRT-DDR-002); items O1 to O3 decided by Amish on 2026-10-02 (TRT-DEC-001)

## Context

The TRL 2 review note (`docs/REVIEW.md`, sessions of 2026-09-24) listed design choices marked "Proposed, awaiting Amish". On 2026-09-25 Amish reviewed the review points for every repo and wrote: "proceed with all of your recommendations across all batches. Make sure we don't proceed to TRL 4 on any of them." Every item that carried a recommendation is therefore decided as recommended. Items without a recommendation stay open.

## Options considered

Table 1. Items with a recommendation.

| # | Item | Options | Recommendation |
| --- | --- | --- | --- |
| D1 | Controller | Single nRF52840 module with built-in IMU, flash and charger (Seeed XIAO nRF52840 Sense class); or a separate nRF52 module and IMU breakout | Single module, no custom PCB |
| D2 | What the band stores | 10 s summaries only; raw data only; summaries with optional raw snippets | Summaries, with optional raw snippets for research |
| D3 | Phone route | Web Bluetooth page; native app | Web Bluetooth page first, native app later |
| D4 | Which wrist | Most affected wrist; both wrists | Most affected wrist first, both later |
| D5 | Data handling | Local-first, owner-controlled export; cloud service | Local-first, no cloud dependency (as R9 requires) |

## Decision

- **D1.** Decided by Amish, 2026-09-25: go with recommendation. One nRF52840 module with built-in LSM6DS3TR-C IMU, 2 MB flash and charger; no custom PCB for the first build.
- **D2.** Decided by Amish, 2026-09-25: go with recommendation. The band stores 32-byte 10 s summaries; a 256 kB area is reserved for raw snippets captured on demand (TRT-CAL-001, section 6).
- **D3.** Decided by Amish, 2026-09-25: go with recommendation. Sync and status use a web Bluetooth page first; a native app may follow.
- **D4.** Decided by Amish, 2026-09-25: go with recommendation. One band on the most affected wrist first; both wrists later.
- **D5.** Decided by Amish, 2026-09-25: go with recommendation. Data stays on the band and the owner's own devices; the owner controls any sharing.

Budget and pitch: the TRL 2 review made no recommendation to change either, so `budget_usd` stays at $150 and the pitch and problem lines are unchanged.

Items left open on 2026-09-25 (no recommendation was made); all three were decided on 2026-10-02 (TRT-DEC-001):

- **O1.** First co-design and validation partner: a movement disorders clinic, a patient association, or the OpenRatio network. **Decided by Amish, 2026-10-02:** the first candidate to approach is an academic movement disorders clinic with its own ethics board, introduced through the OpenRatio network, with the International Essential Tremor Foundation as the route to participants, shared with StillBand and SteadySleeve.
- **O2.** Confirmation of "OpenRatio" as a possible partner (part of O1). **Decided by Amish, 2026-10-02:** confirmed, described in soft, non-clinical wording as a research and educational network.
- **O3.** Approval of kit 1.3.1, whose forearm-for-scale rule for small objects replaces the 1.75 m person in the concept media. **Decided by Amish, 2026-10-02:** approved.

New item raised at TRL 3 (not part of the 2026-09-25 decision):

- **O4.** Charge current: the 50 mA setting (0.33 C, about 3.6 h, about 65 mW charger heat) or the 100 mA setting (0.67 C, about 1.8 h, about 130 mW). Recommendation: 50 mA, to keep the pod cool. Decided by Amish, 2026-09-25: go with recommendation (TRT-DDR-002).

## Consequences

- TRT-REQ-001 v0.3: R5 now counts 7 days at 16 h of wear per day alongside a raw-snippet reserve; R11 names the LED and the web Bluetooth page; the assumptions name the most affected wrist.
- TRT-PRC-001 v0.4: D1, D2, D3 and D5 are recorded as decided; first-order numbers are replaced by TRT-CAL-001 values.
- TRT-PRB-001 v0.3: the wrist question is closed; the partner question stays open.
- The design stops at TRL 3. TRL 4 is on hold by Amish's instruction.

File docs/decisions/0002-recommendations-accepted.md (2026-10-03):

---
doc_id: TRT-DDR-002
title: TremorTrace recommendations accepted
project: TremorTrace
doc_type: Design decision record
version: "0.2"
status: Draft
date: '2026-10-02'
author: Amish Chadha
license: CERN-OHL-S-2.0
revisions:
- version: "0.1"
  date: '2026-09-25'
  author: Amish Chadha
  change: Record Amish's acceptance of all open recommendations (2026-09-25)
- version: "0.2"
  date: '2026-10-02'
  author: Amish Chadha
  change: O1 to O3 recorded as decided by Amish on 2026-10-02
---
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

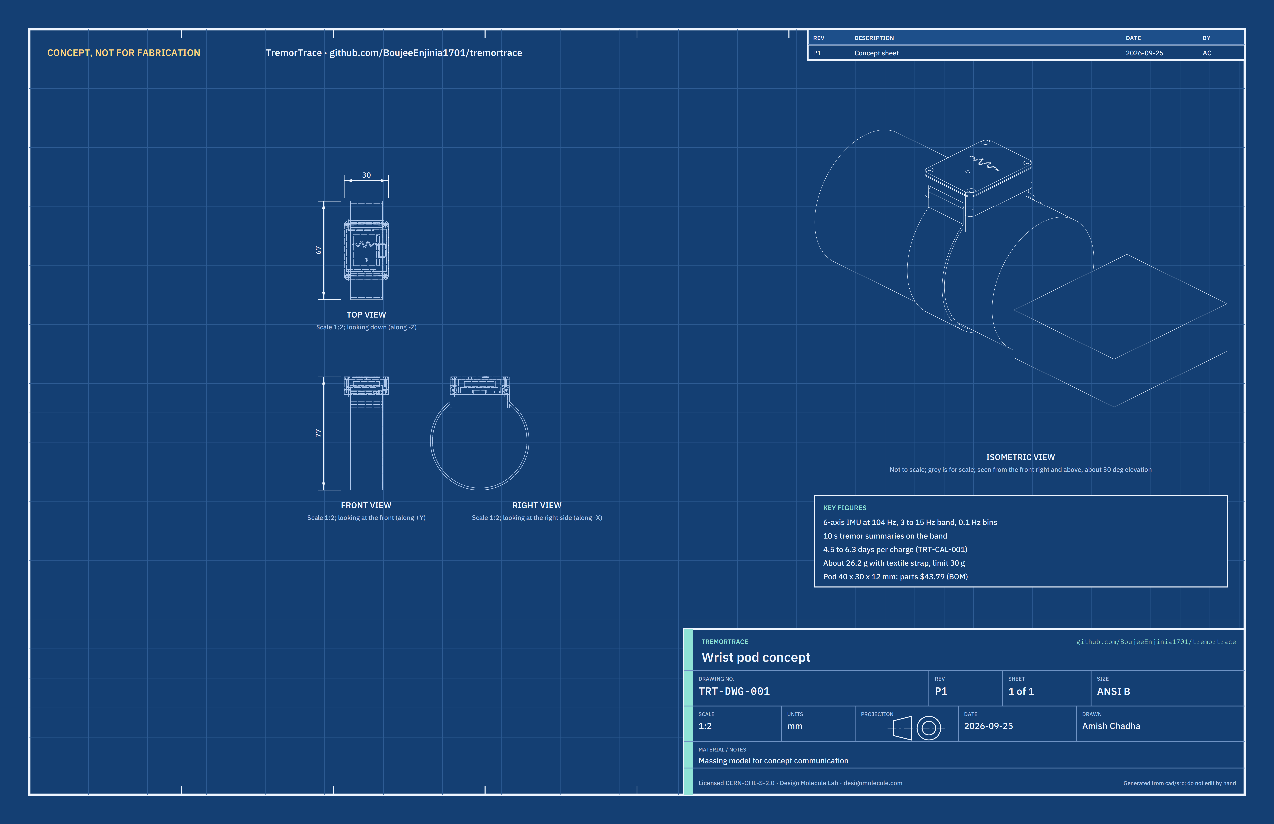
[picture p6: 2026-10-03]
media/concept-blueprint.png

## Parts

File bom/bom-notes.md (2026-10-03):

# BOM notes

Every line in `bom/bom.csv` is priced (TRL 3). The parts total is USD 43.79 per band, checked by `docs/04-calcs/sizing.py`. Value-engineering target: USD 150 (`budget_usd` in `project.yaml`, a hypothetical control target, not a limit); the estimate is USD 106.21 under it. TRT-DDR-003 (design for construction) changed lines 2, 4, 5, 7, 8, 9 and 11 (USD 43.69 for 11 lines); line 12, a Schottky diode at USD 0.10, was added on 2026-10-02 (A2), giving USD 43.79 over 12 lines. Lines changed by TRT-DDR-003: four countersunk lid screws in place of two, the cell plug removed, ribs and a glue collar in the base, foam pads and epoxy in the consumables. Item 1 is a woven textile strap of about 8 g, which replaced the 12 g silicone strap under TRT-DDR-002 to restore mass margin under R6. Item numbers 1 to 8 match the exploded view and drawing TRT-DWG-002.

The LiPo cell price, size and mass were checked against the Adafruit product 1317 listing on 2026-09-25. Other prices are indicative and are confirmed at order. Suppliers are named where a specific part is intended; otherwise a supplier type is given.

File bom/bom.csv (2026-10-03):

item | qty | spec | supplier | unit_cost_usd | make_buy | notes
1 Textile watch strap | 1 | 22 mm two-piece quick-release, woven nylon, skin-safe, washable, about 8 g | Online retailer (watch straps) | 10.00 | buy | Indicative price; quick-release bars fit the 22 mm lugs. Replaces the 12 g silicone strap per TRT-DDR-002 (D7)
2 Enclosure lid | 1 | 3D-printed PETG, 30 x 40 x 1.5 mm, 4 countersunk screw holes, 2 mm light pipe bore | Self (FDM printer) | 0.50 | make | Material about 2.2 g; price includes failed-print allowance
3 Controller and IMU module | 1 | Seeed Studio XIAO nRF52840 Sense: nRF52840, LSM6DS3TR-C IMU, 2 MB QSPI flash, BQ25101 charger | Seeed Studio or distributor | 15.99 | buy | Indicative list price; confirm at order. Decided by Amish 2026-09-25 (TRT-DDR-001)
4 LiPo cell | 1 | 150 mAh 3.7 V protected, 19.75 x 26.02 x 3.8 mm, 4.65 g, JST-PH lead | Adafruit (product 1317) or distributor | 5.95 | buy | Price and size from the Adafruit listing checked 2026-09-25; charge at 150 mA or less. Its plug is cut off and the leads soldered to the module's battery pads (TRT-DDR-003)
5 Enclosure base | 1 | 3D-printed PETG, 30 x 40 x 10 mm, integrated 22 mm lugs with 1.0 mm spring bar holes, cell locating ribs, receptacle glue collar | Self (FDM printer) | 0.50 | make | Material about 4.9 g; price includes failed-print allowance
6 Magnetic pogo charging connector | 1 | 2-pin magnetic receptacle (about 4 x 8 x 3 mm) with USB cable | Online retailer (electronics) | 6.00 | buy | Indicative price
7 Gasket | 1 | 3D-printed TPU 95A perimeter ring, printed 0.8 mm, 0.5 mm compressed, 4 screw holes | Self (FDM printer) | 0.25 | make | Material cost only
8 Spring bars | 1 | Pair, 22 mm quick-release, 1.5 mm body, tips about 0.9 mm (spare set) | Watch parts supplier | 1.00 | buy | Indicative price
9 Lid screws | 4 | M2 x 6 countersunk thread-forming for plastics, stainless | Fastener supplier | 0.25 | buy | One in each lug horn (TRT-DDR-003; was 2 x M2 x 6 pan head on the centre line). Indicative price
10 Light pipe | 1 | 2 mm clear acrylic rod, 2 mm long | Plastics or electronics supplier | 0.50 | buy | Indicative price
11 Consumables | 1 | Two foam pads (0.5 mm adhesive, 2 mm closed-cell), polyimide tape, 26 AWG silicone wire, heat shrink, two-part epoxy | Electronics supplier | 2.00 | buy | Indicative allowance
Schottky diode | 1 | Schottky diode, SOD-123, 1 A, 30 V or higher, forward drop 0.4 V or less at 50 mA (SS14 class) | Electronics distributor | 0.10 | buy | In the charging receptacle's positive lead, on every band (TRT-DDR-003 A2, decided 2026-10-02). A few cents each in volume; USD 0.10 allowance for a single buy. Glued to the base floor beside the receptacle collar.

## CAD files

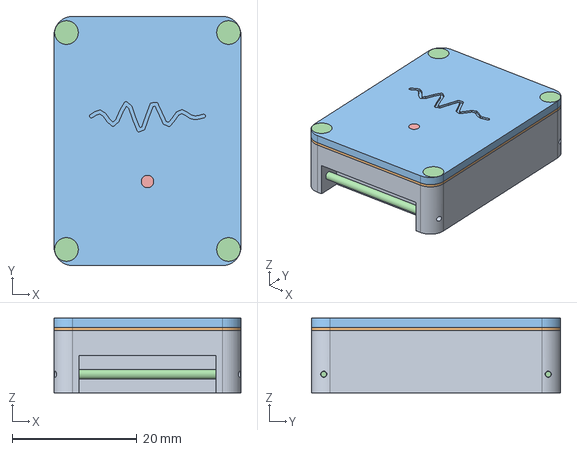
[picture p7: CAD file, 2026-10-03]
cad/step/tremortrace-pod-assembly.step
30.0 x 40.0 x 12.0 mm

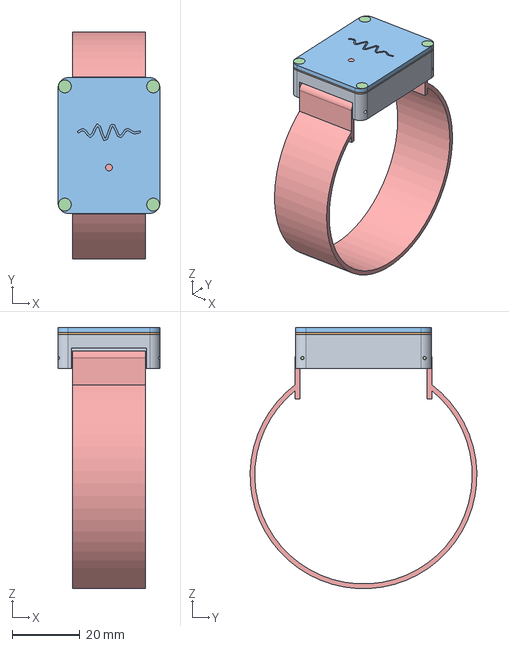
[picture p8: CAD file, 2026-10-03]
cad/step/tremortrace-on-strap.step
30.0 x 66.8 x 76.8 mm

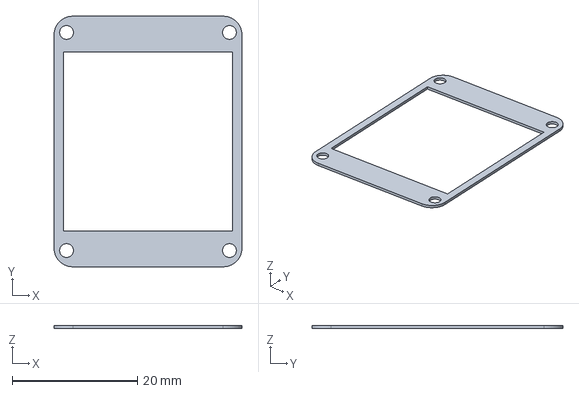
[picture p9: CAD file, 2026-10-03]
cad/step/tremortrace-gasket.step
30.0 x 40.0 x 0.5 mm

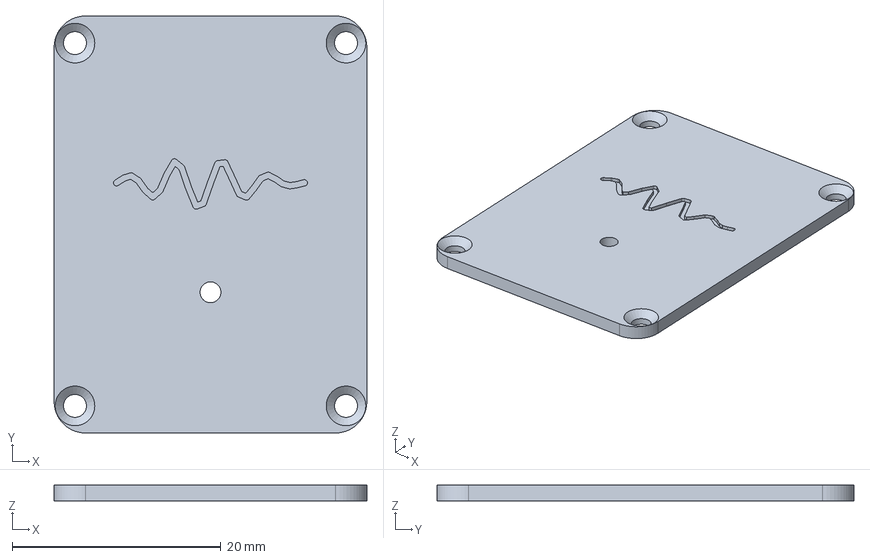
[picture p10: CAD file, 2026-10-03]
cad/step/tremortrace-lid.step
30.0 x 40.0 x 1.50 mm

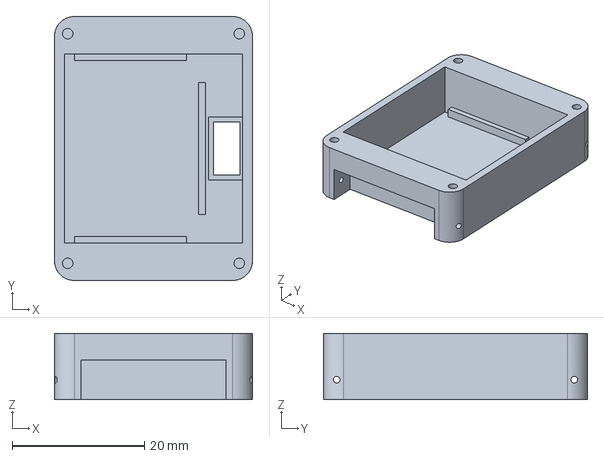
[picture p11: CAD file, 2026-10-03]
cad/step/tremortrace-base.step
30.0 x 40.0 x 10.0 mm

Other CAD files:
cad/stl/tremortrace-base.stl
cad/stl/tremortrace-gasket.stl
cad/stl/tremortrace-lid.stl
cad/stl/tremortrace-pod-assembly.stl

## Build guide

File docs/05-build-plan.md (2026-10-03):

---
doc_id: TRT-BLD-001
title: TremorTrace prototype build plan
project: TremorTrace
doc_type: Build plan
version: "0.2"
status: Draft
date: '2026-10-02'
author: Amish Chadha
license: CERN-OHL-S-2.0
revisions:
  - version: "0.1"
    date: '2026-10-02'
    author: Amish Chadha
    change: First build plan; design made constructable (TRT-DDR-003)
  - version: "0.2"
    date: '2026-10-02'
    author: Amish Chadha
    change: 'Schottky diode added to the wiring, step 1, step 4 and safety stop S3; firmware loaded before the lid is closed, updates over Bluetooth; pictures redrawn (TRT-DEC-001, 2026-10-02)'
---

# TremorTrace prototype build plan

**Plan, not yet built.** How to build the first proof-of-concept prototype, component by component. Building and testing to it is TRL 4 work. Decisions still to be made are kept in the design decisions register ([docs/06-design-decisions.md](06-design-decisions.md)), not here.

> **Safety:** TremorTrace is a research and educational prototype, not a medical device. It has not been cleared or approved by any regulator and must not be used to diagnose, treat or monitor any person. It holds a small lithium polymer cell that sits against the skin: use a protected cell, never charge the band while it is worn, charge only at the 50 mA setting, and stop using it if the pod becomes warm or swollen.

## 1. What you are building

Figure 1. Every component, pulled apart and numbered in build order

*Figure 1. Every component pulled apart and numbered in build order; only the looped ends of the two strap halves are drawn.*

The prototype is one TremorTrace band: a small printed pod, 30 mm along the forearm, 40 mm across the wrist and 12 mm high, on a standard 22 mm two-piece watch strap. Inside the pod a bought module (which carries the motion sensor, radio, memory, charger and status light) sits on a flat 150 mAh cell, with a foam pad above and below so the lid clamps the stack. A magnetic charging receptacle is set into the floor, and a short clear rod in the lid carries the status light out. Figure 1 shows the 13 components in the order you make or fit them. Four are made: the base, the lid with its light pipe and the gasket are 3D printed, and the two foam pads are cut from sheet. The rest are bought and fitted: the module, cell, receptacle, screws, spring bars and strap. The work is printing PETG and TPU, drilling small holes by hand, cutting foam, soldering four wires and one small diode and mixing a little epoxy. The parts cost about USD 44 from the bill of materials.

## 2. What changed to make it buildable

The concept showed what the band does; some of its parts could not be made or fixed as drawn. Each change below keeps what the band does, and all of them are recorded in decision record TRT-DDR-003, open for Amish's review.

*Table 1. Changes from the concept.*

| Component | The concept had | The buildable design has | Why |
| --- | --- | --- | --- |
| Spring bar holes | 1.8 mm holes, wider than the 1.5 mm bar body | 1.0 mm holes that take only the bar's thin tips (Figure 5) | The bar can no longer slide sideways and drop out |
| Lid screws | Two screws on the centre line, right above the strap notches, with no plastic below the screw tips | Four countersunk screws, one in each solid corner (lug horn), 4 mm of thread each (Figure 8) | Solid plastic to screw into; the gasket is squeezed at all four corners; the heads sit flush |
| Strap notches | 4.0 mm deep; the strap loop rubbed the inner face | 4.5 mm deep (Figure 5) | The looped strap end swings freely, 0.35 mm clear |
| Charging receptacle | Sat in a floor hole with no fixing | A printed collar round the hole, filled with epoxy (Figure 4) | The epoxy both holds and seals the only hole through the skin side |
| Cell | Free to slide inside the pod | Three low printed ribs make a pocket 0.3 mm larger than the cell (Figure 3) | The cell stays put and the wires have room beside it |
| Module | Floated with a 1.7 mm gap under the lid | A 2 mm foam pad above it, squeezed by the lid (Figure 7) | The lid clamps the whole stack; nothing rattles |
| Charging receptacle lead | Receptacle wired straight to the module's 5 V and ground pins | A small Schottky diode in the receptacle's red lead, glued to the floor beside the collar (Figure 11) | The contacts touch the skin; the diode blocks any voltage from the module reaching them |
| Cell plug | A plug with no room for it in the pod | Plug cut off; leads soldered to the module's battery pads (Figure 11) | Nothing bulky in the 9.5 mm high cavity |
| Light pipe and gasket | A bore with no rod; a gasket drawn only squeezed | A 2 mm clear rod set in epoxy; a gasket printed 0.8 mm thick that squeezes to 0.5 mm | Every part is now drawn and checked for fit |

## 3. Making the components

Make and check each component before the assembly step that needs it. Sizes are in millimetres. The pod's "hand end" and "elbow end" are its two short sides along the forearm; its "strap ends" are the two 30 mm faces where the strap fits. Printing tolerance is about 0.2 mm; open every small hole with a drill rather than trusting the printed size. Drawings do not carry tolerances before TRL 4.

### 3.1 Enclosure base

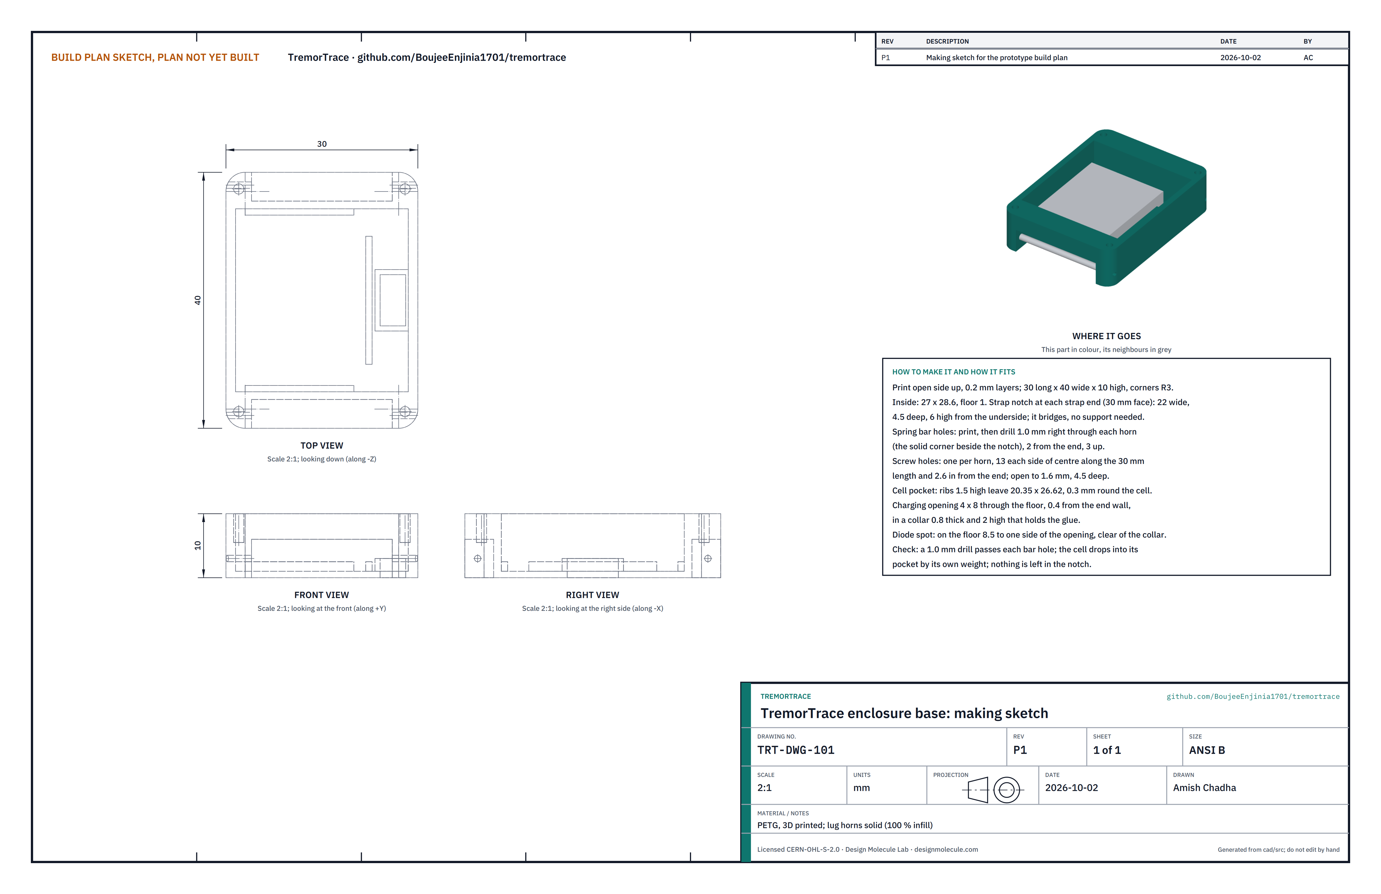
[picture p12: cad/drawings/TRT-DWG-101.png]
Figure 2. Making sketch of the enclosure base


*Figure 2. Enclosure base making sketch (TRT-DWG-101).*

**What it is and what it is made from.** The open box that holds everything, with the two strap lugs built in. PETG, 3D printed, 30 x 40 x 10 mm with 3 mm rounded corners, walls 1.5 thick and a 1 mm floor. The four solid corners beside the strap notches (the lug horns) must print solid.

**How to make it.**

1. Print open side up, 0.2 mm layers, at least four walls, with the lug horns at 100 % infill (use a modifier, or 100 % infill for the whole part). The strap notch at each strap end, 22 wide, 4.5 deep and 6 high from the underside, bridges without support.
2. Inside the box, check the cell pocket printed clean: three ribs 1.5 high and 1 wide (one across the box toward the hand end, one along each long side) which with the elbow-end wall leave a pocket 20.35 x 26.62.
3. Check the 4 x 8 charging opening through the floor at the hand end, 0.4 from the end wall, inside a collar 0.8 thick and 2 high. Clear any stringing from the opening.
4. Spring bar holes: with a 1.0 mm drill in a pin vise, drill right through each lug horn along the forearm, 2 from the strap end and 3 up from the underside. Drill from the outside of each horn toward the notch.
5. Screw holes: one in the top of each lug horn, 13 each side of the centre along the forearm and 2.6 in from the strap end. Open each to 1.6 mm, 4.5 deep. Do not go deeper; the spring bar hole is 2 mm below.
6. Deburr every hole with a sharp blade.

**How it fits the parts next to it.**

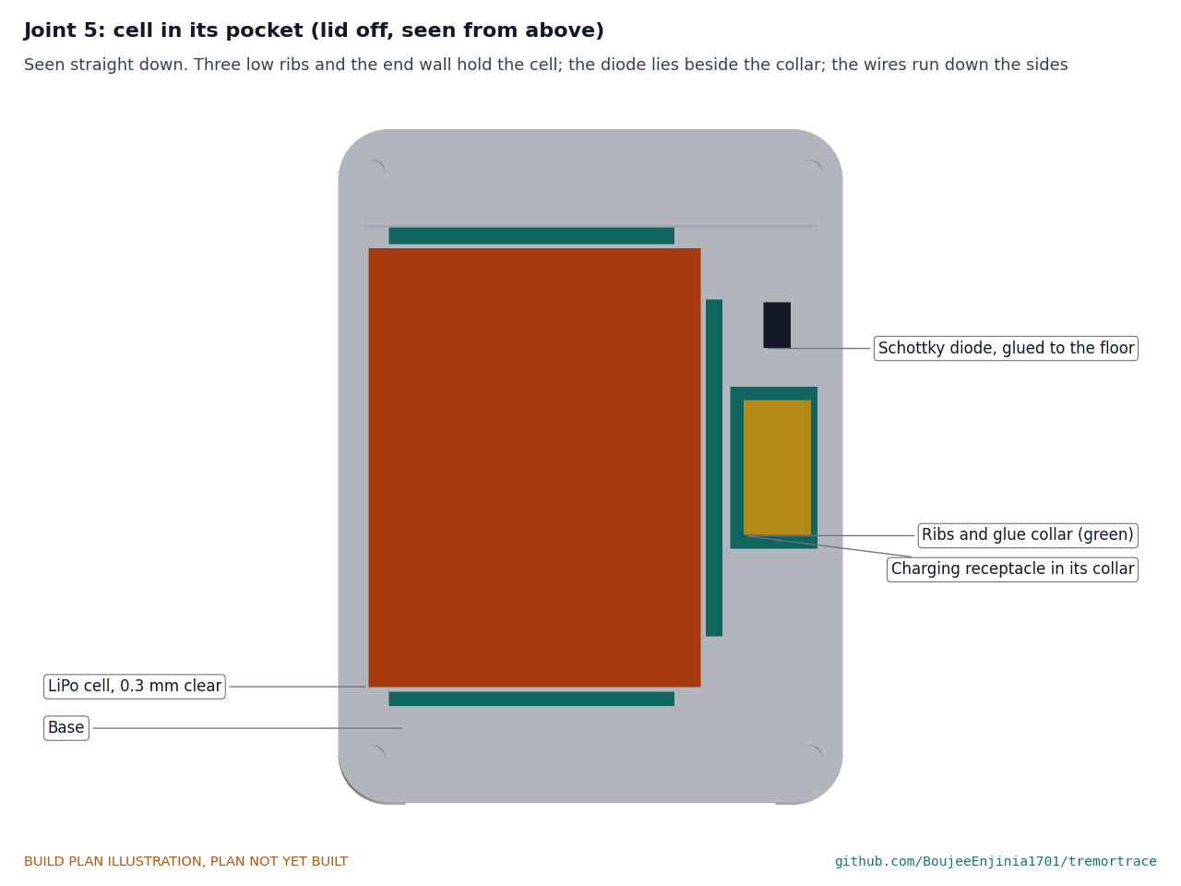
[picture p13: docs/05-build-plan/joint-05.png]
Figure 3. Joint 5: the cell in its pocket


*Figure 3. The cell drops into the pocket made by the three ribs and the elbow-end wall, 0.3 mm clear all round; the receptacle sits in its collar at the hand end.*

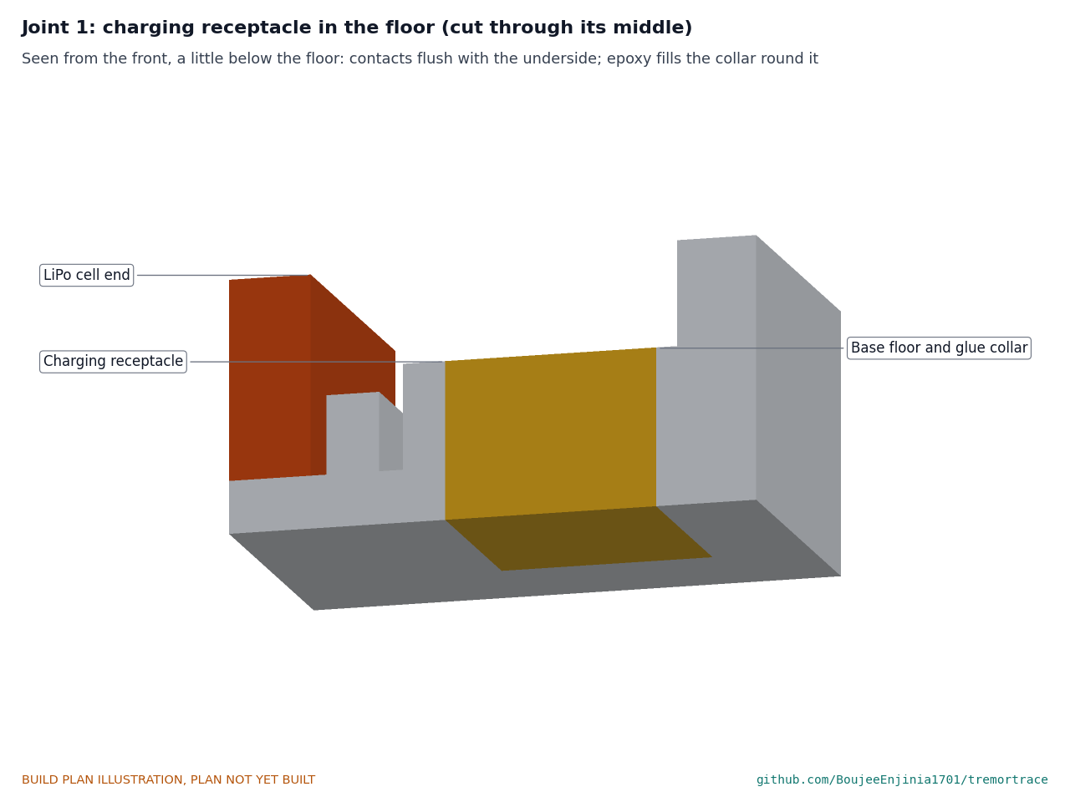
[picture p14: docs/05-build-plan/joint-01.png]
Figure 4. Joint 1: charging receptacle in the floor


*Figure 4. The receptacle goes up through the floor opening with its contacts flush with the underside; epoxy fills the collar round it.*

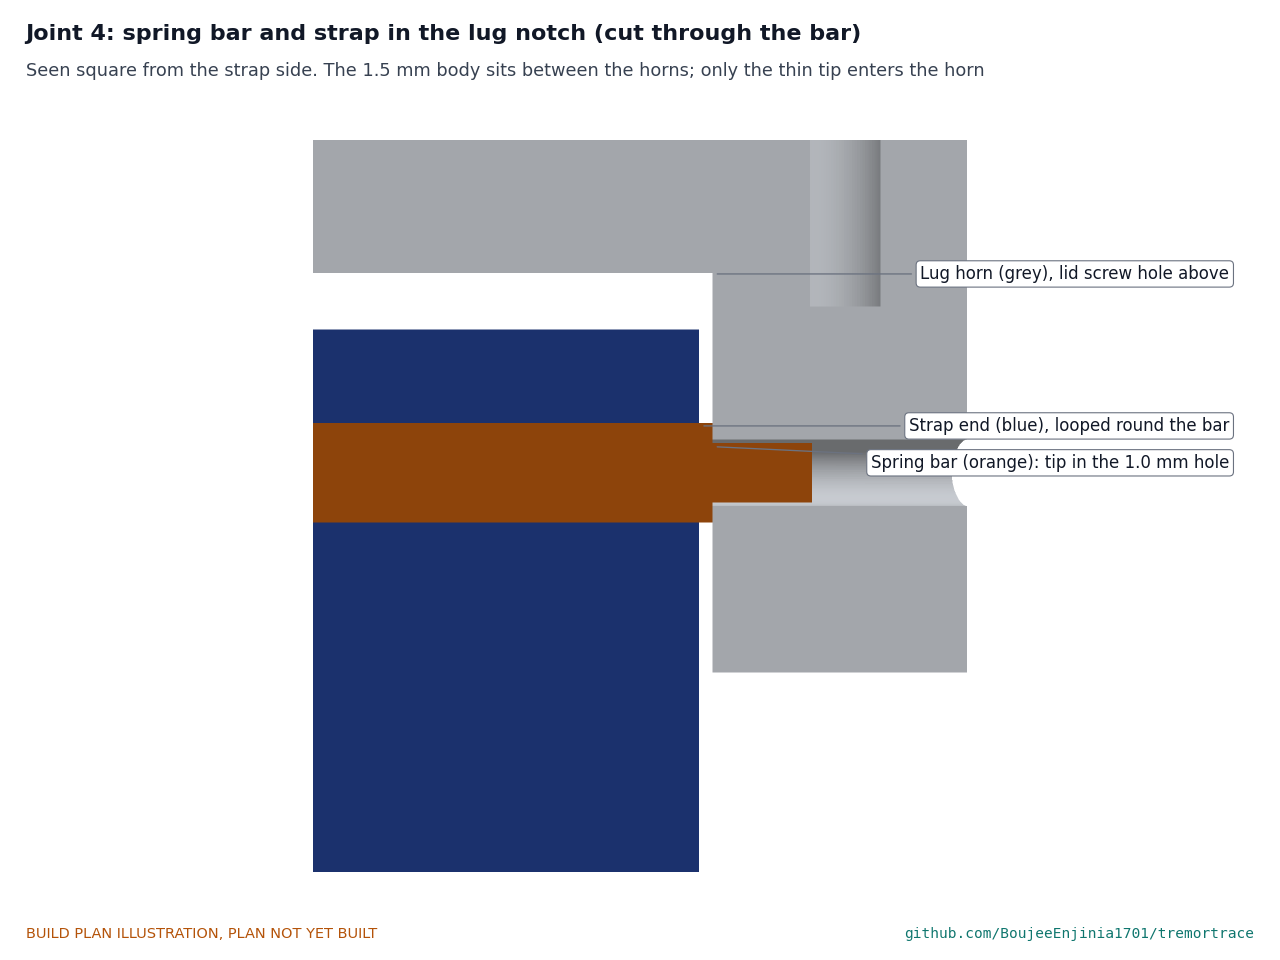
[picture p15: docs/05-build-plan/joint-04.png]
Figure 5. Joint 4: spring bar and strap in the notch


*Figure 5. The bar's body sits between the horns; only its thin tip goes into the 1.0 mm hole. The strap end loops round the bar inside the notch.*

**Check before moving on.** A 1.0 mm drill passes each spring bar hole; a 1.6 mm drill reaches 4.5 deep in each screw hole; the cell drops into its pocket under its own weight; nothing is left in the notches or the opening.

### 3.2 Lid and light pipe

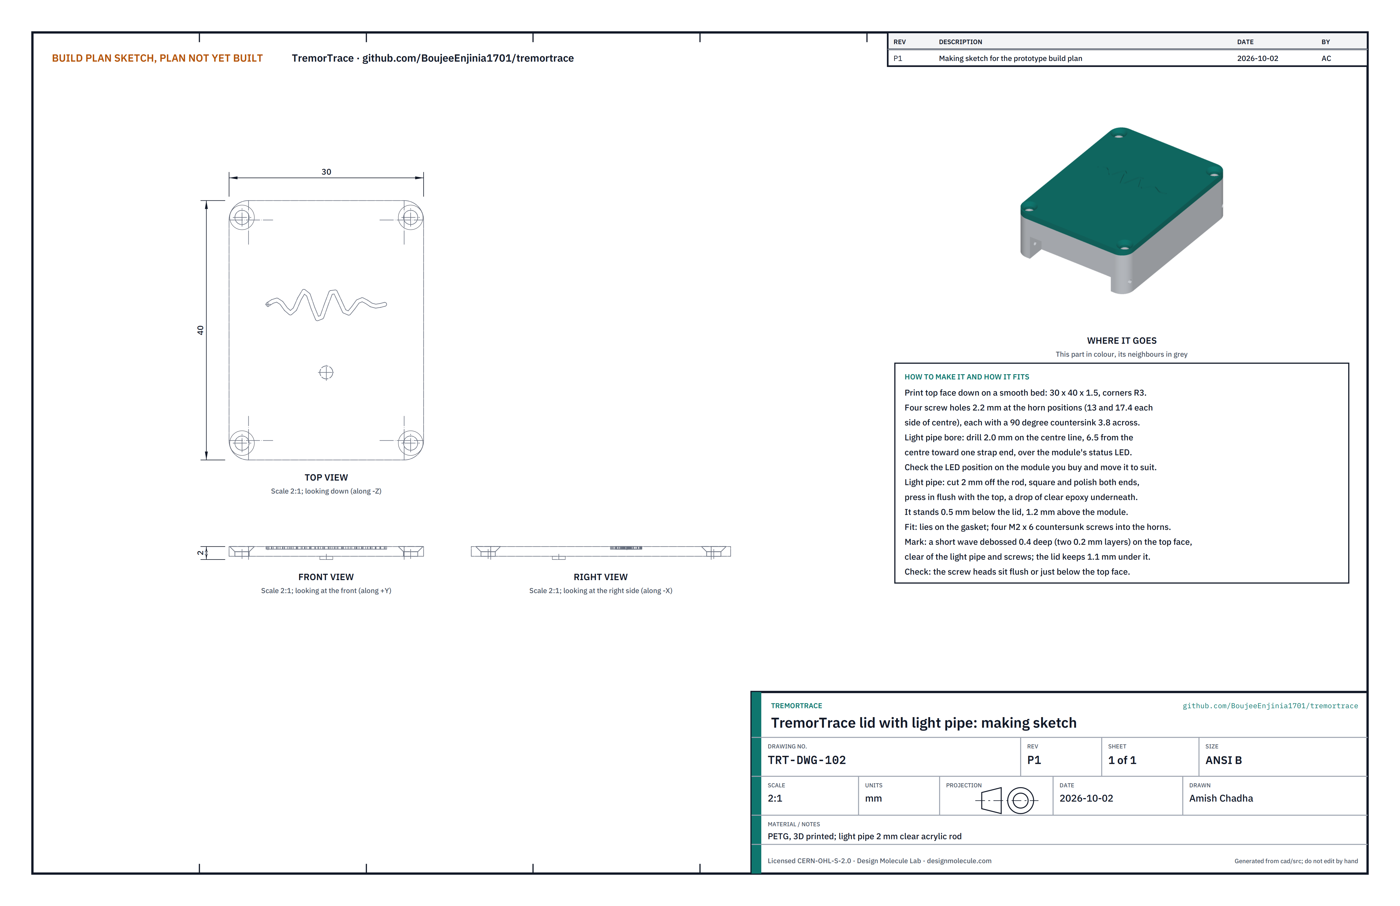
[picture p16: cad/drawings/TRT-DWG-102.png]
Figure 6. Making sketch of the lid


*Figure 6. Lid with light pipe making sketch (TRT-DWG-102).*

**What it is and what it is made from.** The flat cover, with four countersunk screw holes and a clear rod that carries the status light out. PETG, 3D printed, 30 x 40 x 1.5 mm with 3 mm corners; the light pipe is a 2 mm length of 2 mm clear acrylic rod.

**How to make it.**

1. Print top face down on a smooth bed so the outside is smooth. Four screw holes 2.2 across at the lug horn positions, each with a 90 degree countersink 3.8 across on the top face.
2. Light pipe bore: drill 2.0 mm on the centre line, 6.5 from the centre toward one strap end, over the module's status light. Check the light's position on the module you have and move the bore to suit.
3. Cut 2 mm off the acrylic rod with a fine saw; square and polish both ends on fine abrasive paper.
4. Fit the light pipe as step 6 describes.

**How it fits the parts next to it.**

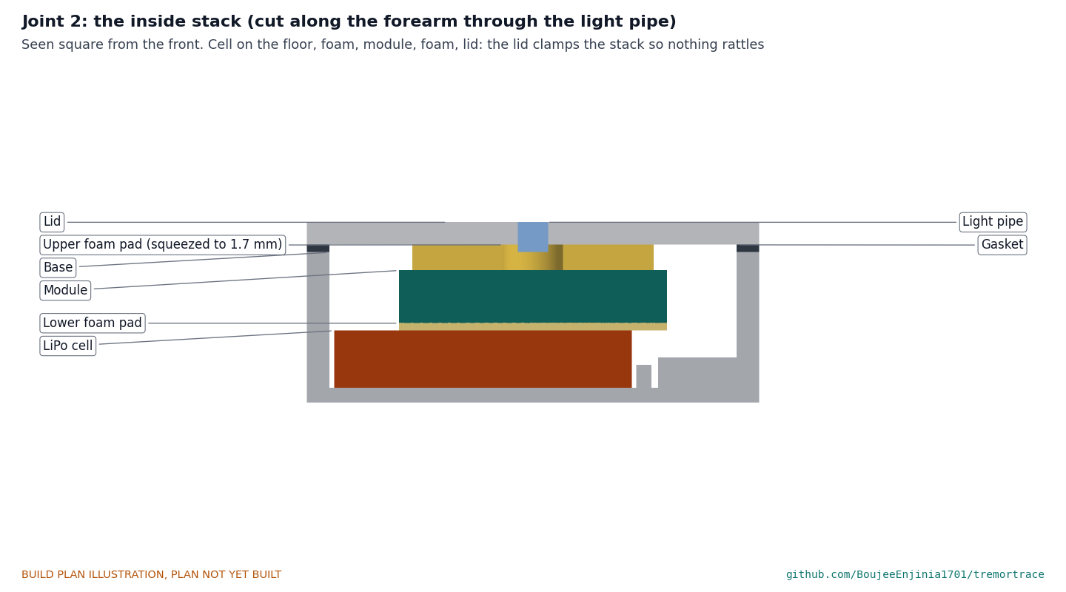
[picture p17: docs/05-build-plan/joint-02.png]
Figure 7. Joint 2: the inside stack


*Figure 7. Cut along the forearm through the light pipe: cell, lower pad, module, upper pad and lid. The light pipe stands 0.5 below the lid and 1.2 above the module.*

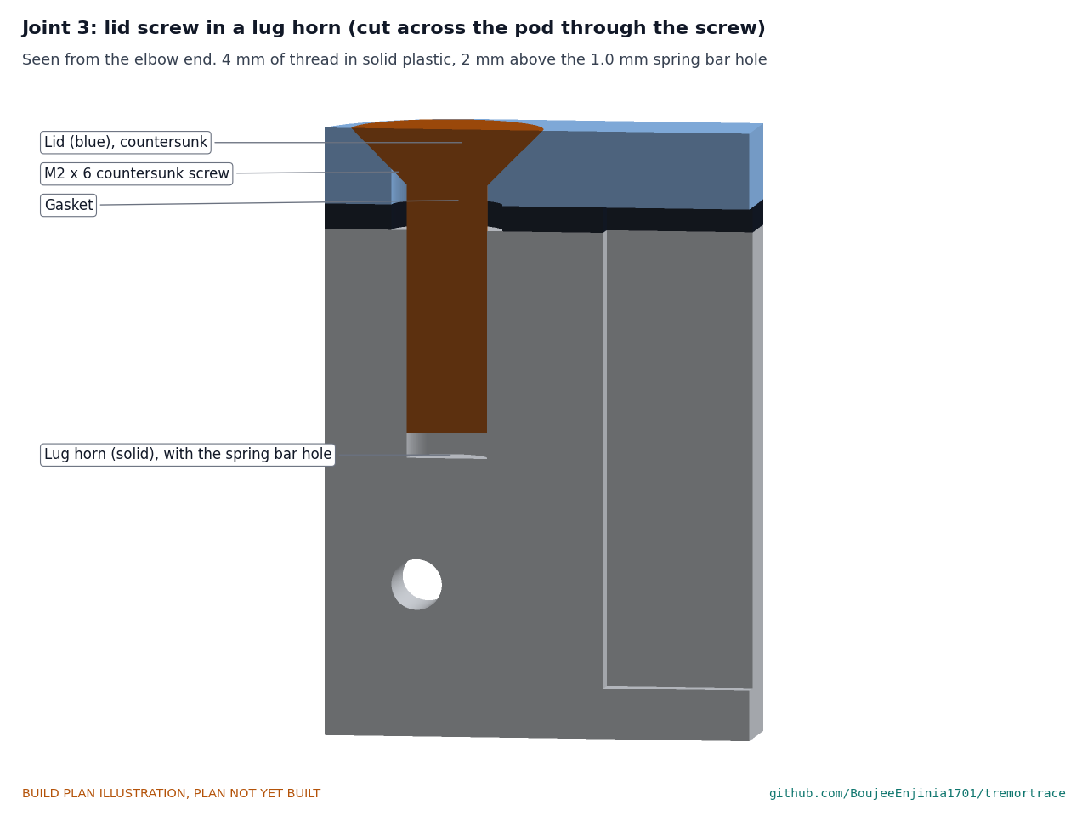
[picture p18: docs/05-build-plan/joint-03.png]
Figure 8. Joint 3: a lid screw in a lug horn


*Figure 8. Cut across the pod through a screw: the screw passes through the lid and gasket into 4 mm of solid horn, 2 mm above the spring bar hole.*

The lid lies on the gasket, and the gasket on the base rim; four M2 x 6 countersunk thread-forming screws go through both into the horns. The upper foam pad presses up against the lid's underside.

**Check before moving on.** The light pipe is flush with the top face and clear from end to end; a test screw head sits flush or just below the top face.

### 3.3 Gasket

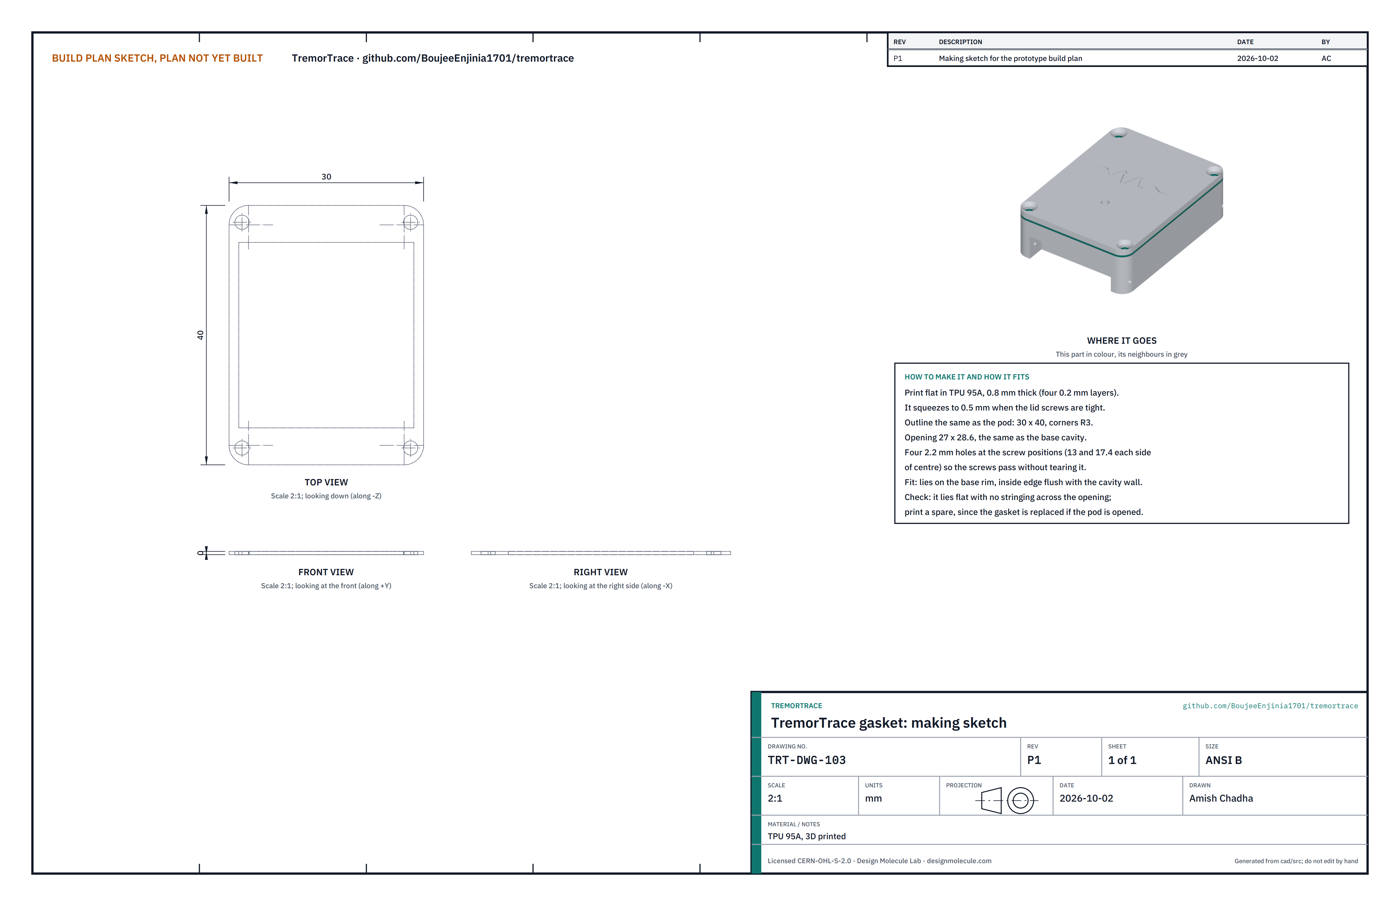
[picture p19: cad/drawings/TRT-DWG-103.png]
Figure 9. Making sketch of the gasket


*Figure 9. Gasket making sketch (TRT-DWG-103).*

**What it is and what it is made from.** The soft ring between the base rim and the lid that keeps splashes out. TPU 95A, 3D printed, 0.8 mm thick, which the lid screws squeeze to 0.5 mm.

**How to make it.**

1. Print flat, four layers of 0.2 mm, slowly (TPU prints best from a direct-drive extruder).
2. Outline 30 x 40 with 3 mm corners, the same as the pod; opening 27 x 28.6, the same as the inside of the base.
3. Four 2.2 mm holes at the screw positions, 13 and 17.4 each side of the centre.
4. Print a spare: a gasket is replaced whenever the pod is opened.

**How it fits the parts next to it.** It lies on the base rim with its inside edge flush with the inside wall and its holes over the screw holes (Figure 8).

**Check before moving on.** It lies flat, with no stringing across the opening and no gaps in the ring.

### 3.4 Foam pads (lower and upper)

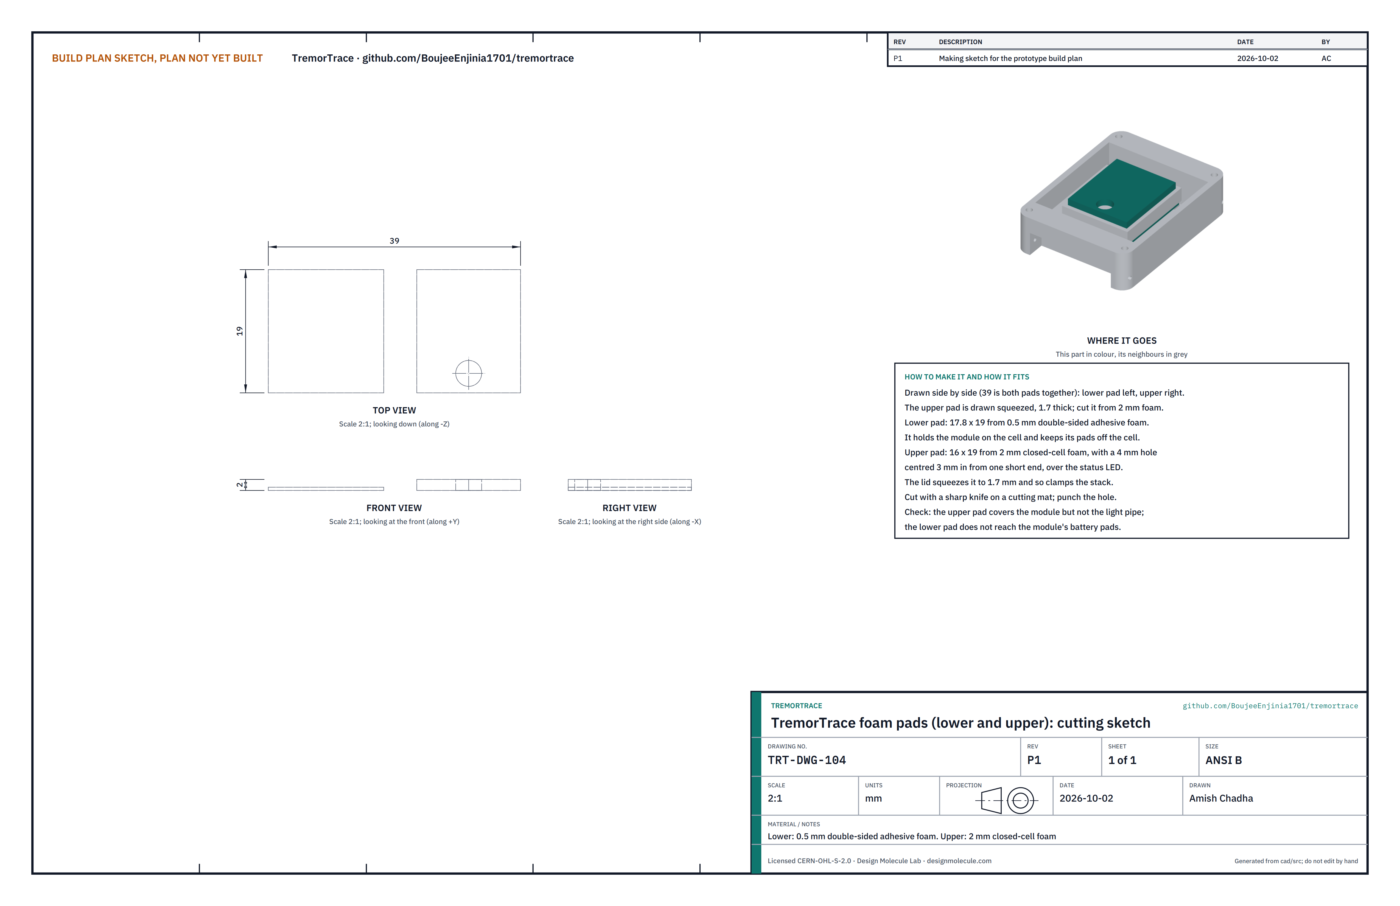
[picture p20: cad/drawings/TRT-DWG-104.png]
Figure 10. Cutting sketch of the foam pads


*Figure 10. Foam pads cutting sketch (TRT-DWG-104).*

**What they are and what they are made from.** Two pads that hold the module: a lower pad of 0.5 mm double-sided adhesive foam that sticks the module to the cell, and an upper pad of 2 mm closed-cell foam that the lid squeezes to 1.7 mm.

**How to make them.**

1. Lower pad: cut 17.8 x 19 with a sharp knife on a cutting mat.
2. Upper pad: cut 16 x 19, and punch a 4 mm hole centred on the long centre line, 3 in from one short end.

**How they fit the parts next to them.** The lower pad covers the cell under the module but stops short of the module's battery pads. The upper pad sits on the module with its hole over the status light, so the light pipe looks straight down at the light (Figure 7).

**Check before moving on.** Laid on the module, the upper pad covers it without hanging over its edges, and the hole sits over the status light.

### 3.5 Bought components

Buy to specification, not brand. Line numbers are those of the bill of materials.

- **Controller and motion sensor module (line 3).** nRF52840 module with a six-axis motion sensor, 2 MB flash, a single-cell charger with a 50 mA setting, battery pads and a status light, about 21 x 17.8 x 3.5 mm (XIAO nRF52840 Sense class).
- **Cell (line 4).** 150 mAh lithium polymer, 3.7 V, with its own protection circuit, about 19.75 x 26.02 x 3.8 mm, from a maker that publishes a datasheet and allows charging at 150 mA or less.
- **Charging receptacle (line 6).** Two-contact magnetic receptacle about 4 x 8 x 3 mm, sold with its matching USB charging cable.
- **Schottky diode (line 12).** SOD-123 surface-mount or similar small part, 1 A, 30 V or higher, forward drop 0.4 V or less at 50 mA; glued to the base floor and soldered into the receptacle's red lead.
- **Lid screws (line 9).** Four M2 x 6 countersunk thread-forming screws for plastics, stainless.
- **Spring bars (line 8).** 22 mm quick-release bars with a 1.5 mm body and tips of about 0.9 mm (one pair usually comes with the strap; keep the spare pair).
- **Strap (line 1).** 22 mm two-piece quick-release woven textile strap, skin-safe and washable, about 8 g.
- **Light pipe (line 10).** 2 mm clear acrylic rod.
- **Consumables (line 11).** 0.5 mm double-sided adhesive foam, 2 mm closed-cell foam, 26 AWG stranded silicone wire in red and black, 1.5 mm heat shrink, polyimide tape, clear two-part epoxy.

## 4. Putting it together

In each picture the parts already fitted are grey and the part being fitted is in colour, with an arrow showing the way it goes in. Step 3 is wiring, shown as a diagram.

### Step 1: charging receptacle into the floor

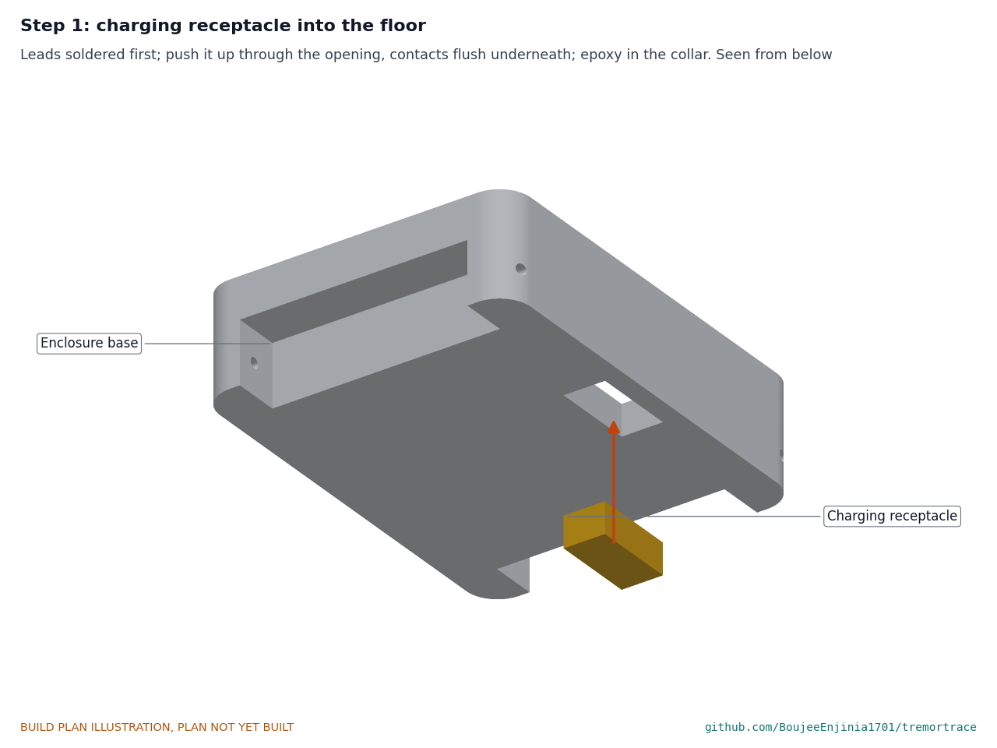
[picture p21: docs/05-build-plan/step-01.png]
Step 1


Solder a 40 mm red lead to the receptacle's positive contact and a black lead to its negative contact. Cut the red lead 15 mm from the receptacle and solder the Schottky diode between the two pieces, with its marked end (the band) toward the module. Cover every joint with heat shrink. Feed the leads up through the floor opening from underneath and push the receptacle up until its contacts are flush with the underside. Fill the collar round it with clear epoxy, keeping epoxy off the contacts, and let it cure flat for the full time on the pack.

### Step 2: cell into its pocket

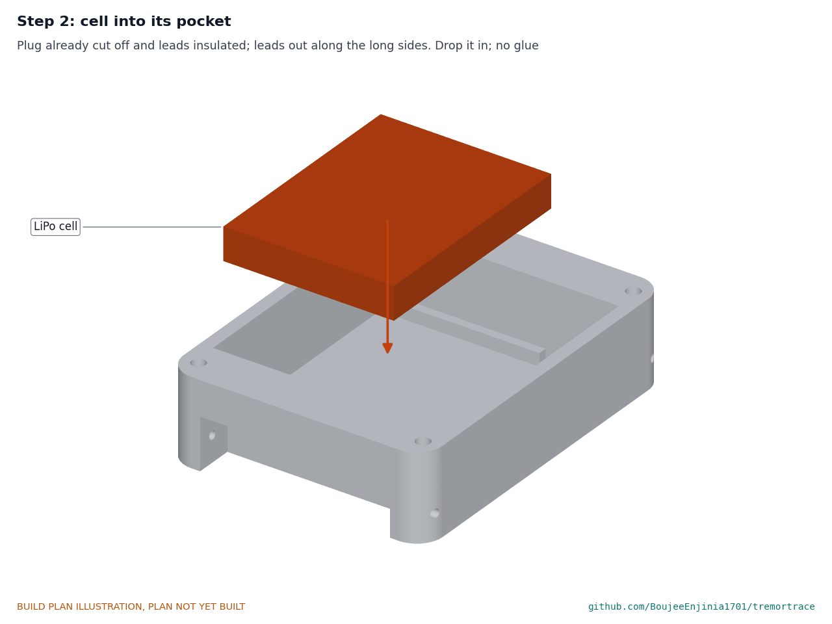
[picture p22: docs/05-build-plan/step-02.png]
Step 2


**Hold point:** safety stop S2. Cut the cell's plug off one lead at a time, never both together, and cover each bare end with tape until it is soldered. Drop the cell into its pocket with its leads coming out along a long side. No glue.

### Step 3: wire the module

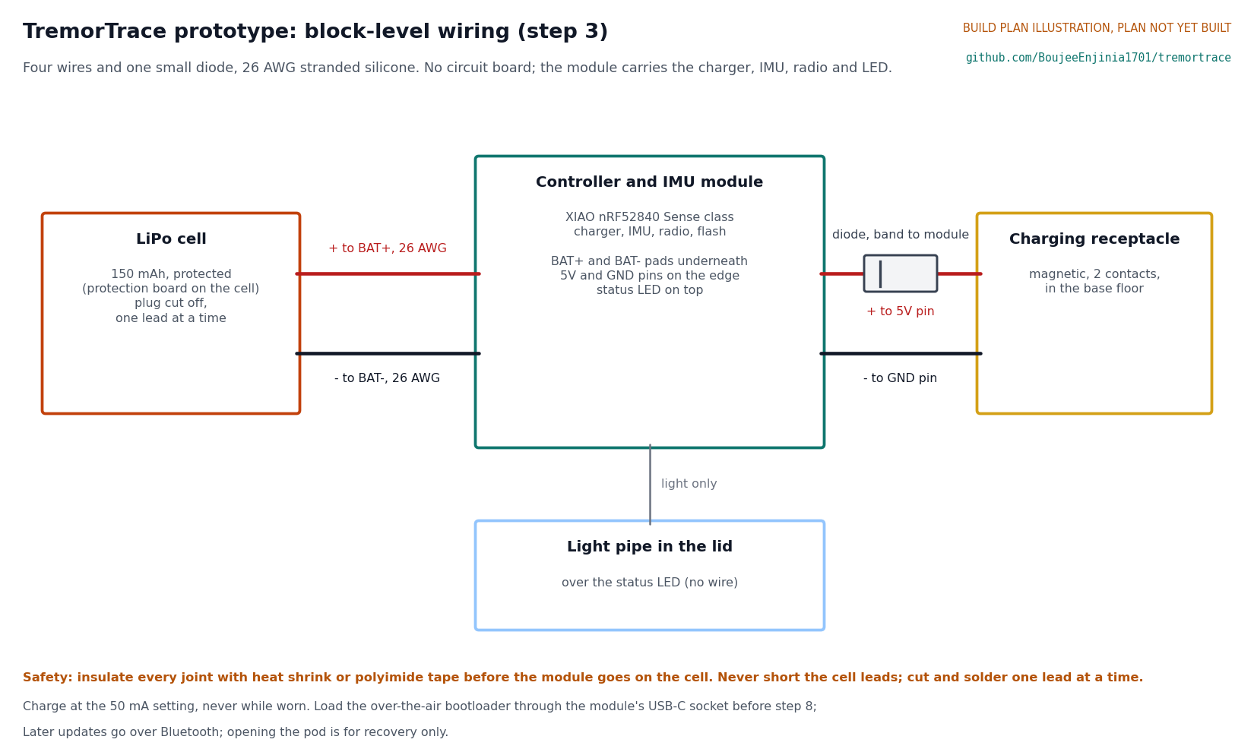
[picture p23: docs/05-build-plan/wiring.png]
Figure 11. Block-level wiring


*Figure 11. Four wires and one diode: cell to the module's battery pads, receptacle through the diode to the module's 5 V pin and straight to its ground pin.*

With the module outside the pod, solder the cell's red lead to the battery positive pad and its black lead to the battery negative pad, one lead at a time; then the receptacle's red lead (the end beyond the diode) to the 5 V pin and its black lead to a ground pin. Keep each lead just long enough to reach with the module lifted out beside the pod. Cover every joint with heat shrink or polyimide tape. Load the over-the-air bootloader (and the first firmware) through the module's USB-C socket now, before the lid is closed: the socket is sealed inside once the lid is on. Later updates go over Bluetooth; opening the pod, with a new gasket, is for recovery only. **Hold point:** safety stops S3 and S4.

### Step 4: lower foam pad and module

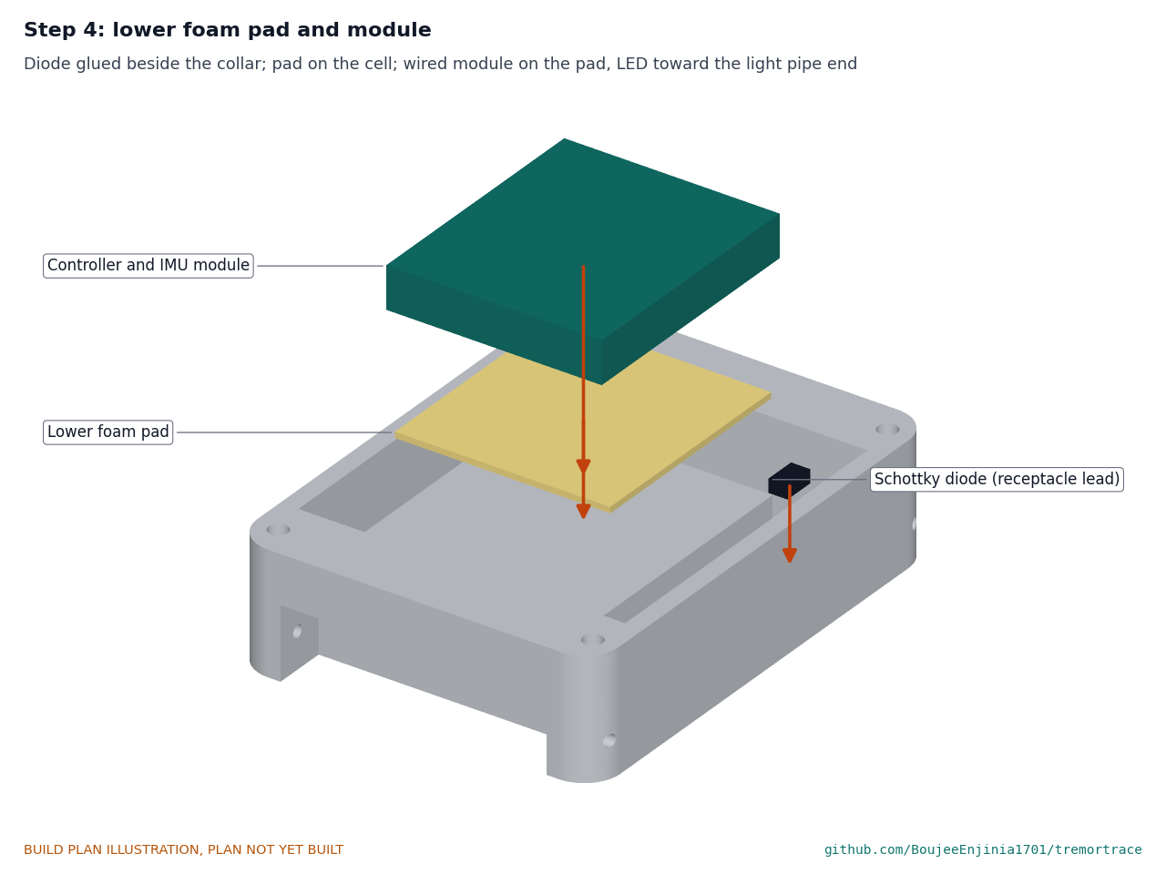
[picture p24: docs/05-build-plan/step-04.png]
Step 4


Stick the lower pad on the cell, peel its top liner, and press the wired module onto it, status light toward the strap end with the light pipe. Glue the diode flat on the floor beside the receptacle collar, 8.5 mm to one side of the opening, with a drop of epoxy, before the module goes in. Tuck the wires into the gaps beside the cell, clear of the gasket rim.

### Step 5: upper foam pad

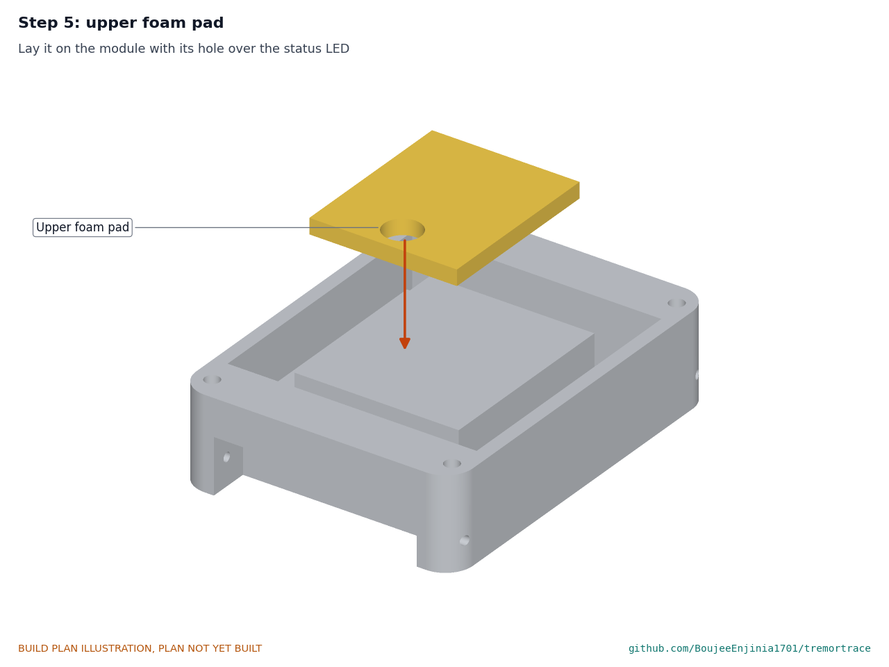
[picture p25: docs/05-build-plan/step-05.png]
Step 5


Lay the upper pad on the module with its hole over the status light.

### Step 6: light pipe into the lid

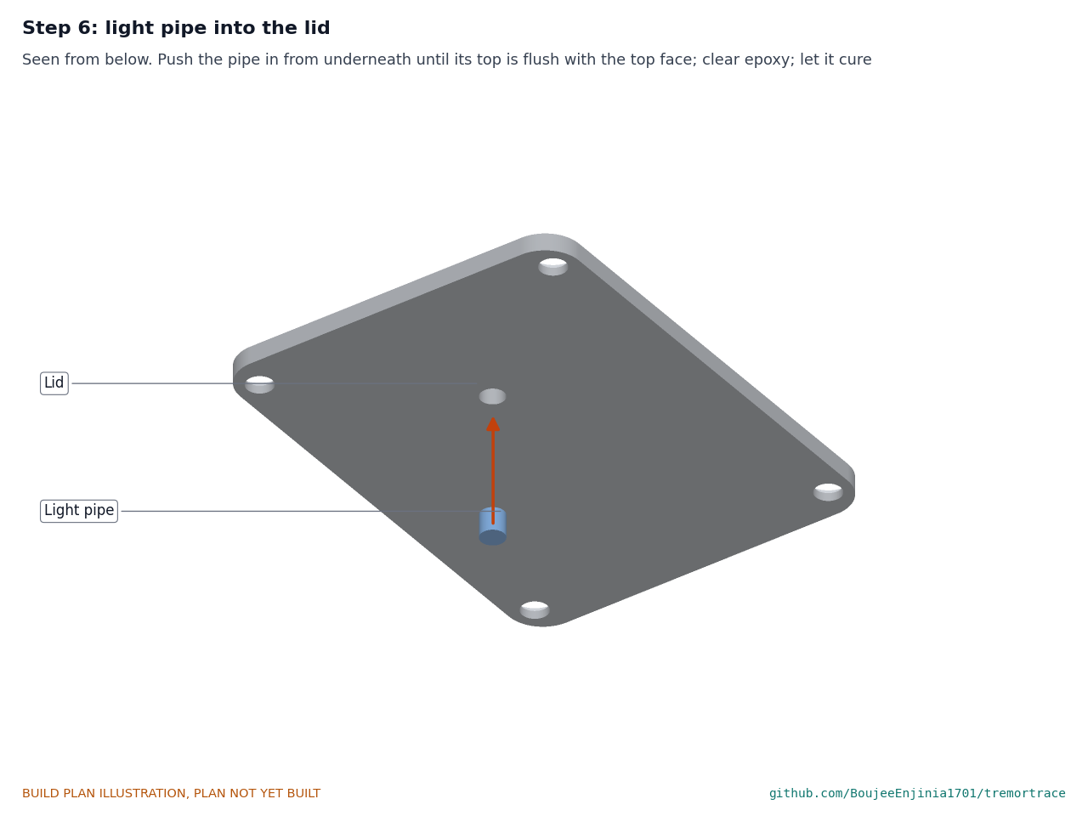
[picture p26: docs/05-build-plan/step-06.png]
Step 6


Lay the lid top face down on a smooth sheet. Push the light pipe into its bore from underneath until it touches the sheet (flush with the top face). Put a small drop of clear epoxy round it on the underside and let it cure.

### Step 7: gasket onto the rim

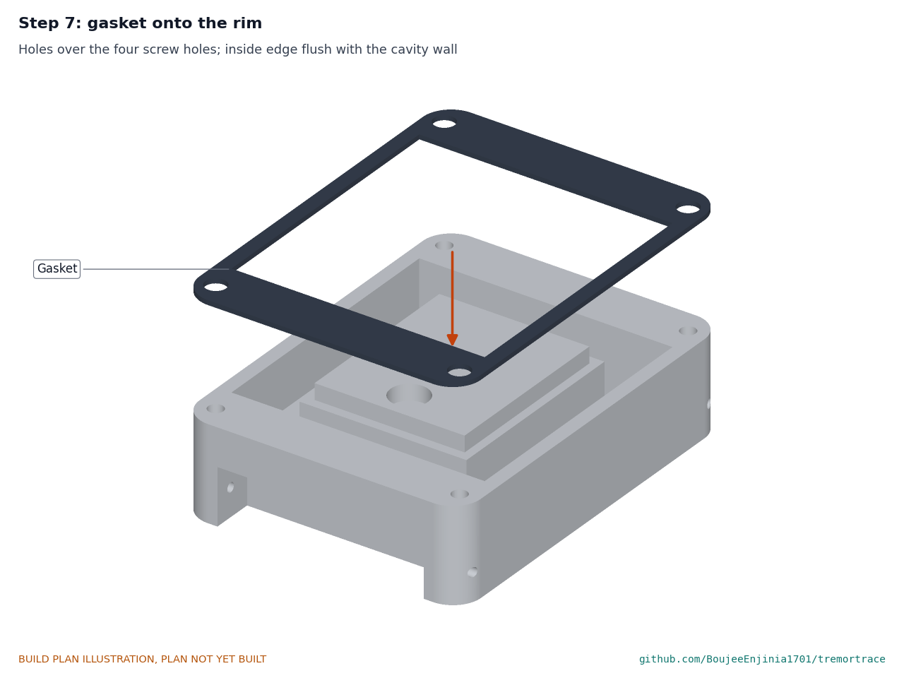
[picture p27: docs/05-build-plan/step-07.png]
Step 7


Lay the gasket on the base rim with its holes over the screw holes and its inside edge flush with the inside wall. **Hold point:** safety stop S5.

### Step 8: lid and four screws

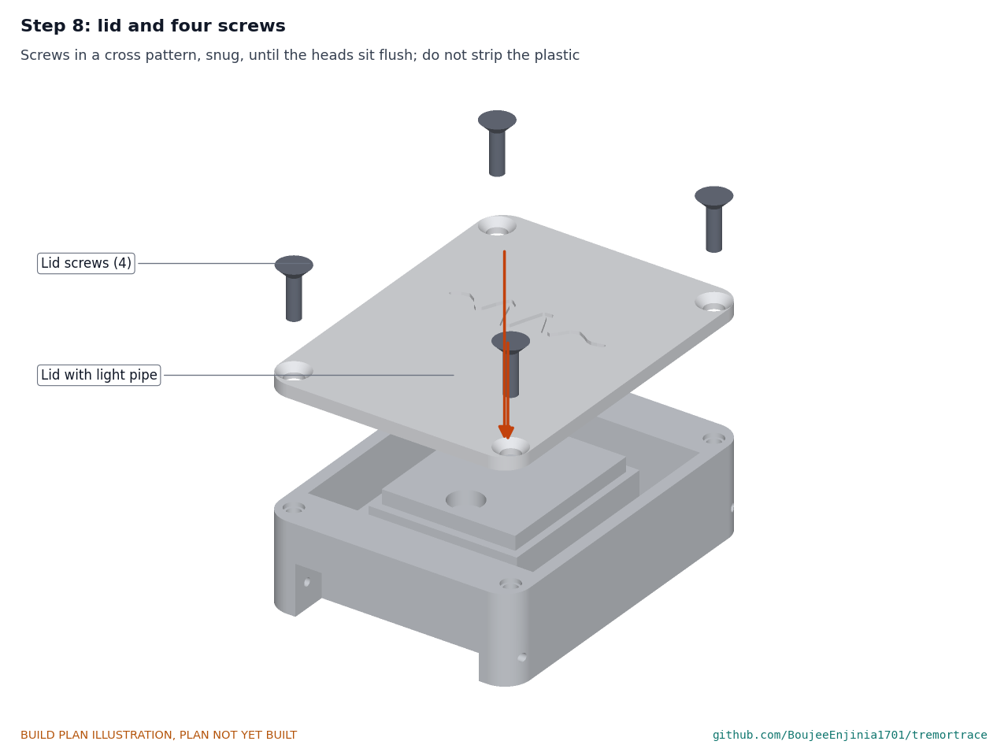
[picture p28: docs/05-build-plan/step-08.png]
Step 8


Place the lid, light pipe over the status light. Drive the four screws in a cross pattern, a turn or two at a time, until the heads sit flush. Stop as soon as they are snug: the thread is cut in plastic and strips if forced.

### Step 9: spring bars and strap halves

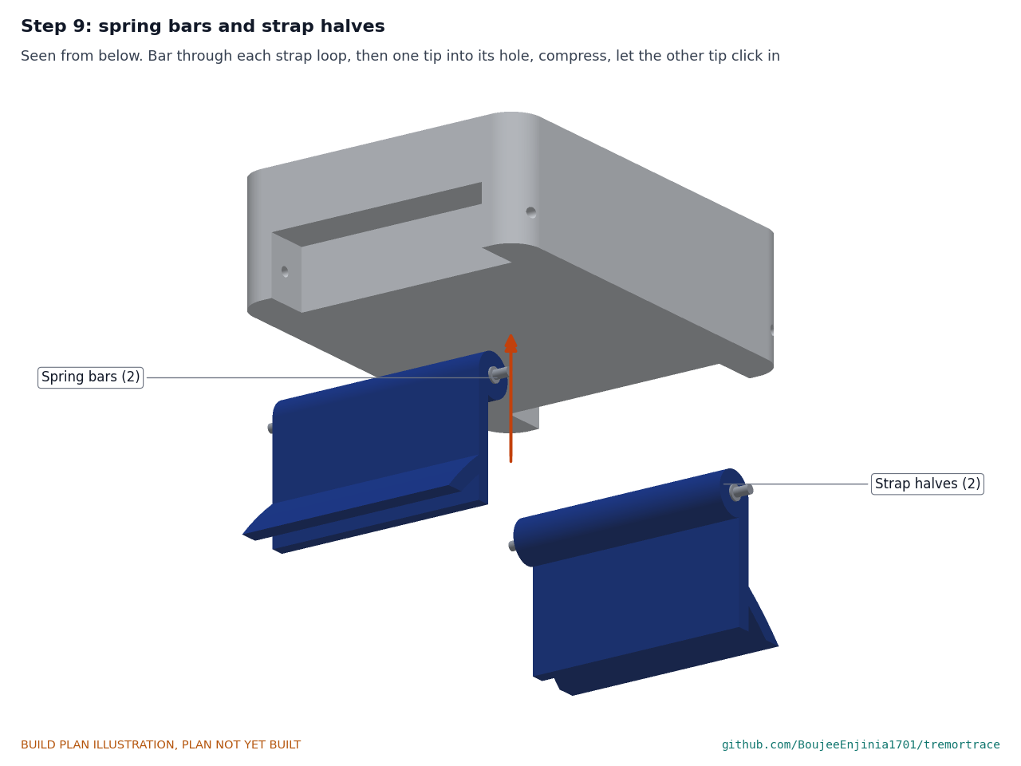
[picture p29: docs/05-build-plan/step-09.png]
Step 9


Pass a spring bar through each strap half's loop. Put one tip into its hole in a horn, compress the bar with a spring bar tool, line up the other tip and let it click into its hole. Pull each strap half firmly to check it is held. **Hold point:** safety stop S6 before the band is worn.

## 5. First checks

These are the checks a TRL 4 test report would record; this plan only lists them. Requirement numbers are those of TRT-REQ-001.

*Table 2. First checks.*

| Check | Requirement | How | Pass when |
| --- | --- | --- | --- |
| Size | R6 | Calipers over the closed pod | 45 x 35 x 14 mm or less (30 x 40 x 12 mm by design) |
| Mass | R6 | Weigh the finished band with its strap on a 0.1 g scale | 30 g or less (26.2 g estimated) |
| Strap held | R7 | Pull each strap half firmly by hand | Neither bar moves or comes out |
| Seal squeeze | R7 | Look at the gasket edge all round under a lamp | Evenly squeezed, no gap; screw heads flush (the splash test comes later) |
| Cell voltage at the module | R4 | Meter on the battery pads before the module is powered up | 3.0 to 4.2 V, correct polarity |
| Status light | R11 | Power the module from the cell; look at the lid | The light shows through the light pipe |
| Charging current | R4 | USB power meter in the charging cable, attended, on the charging spot of S1 | 60 mA or less, falling as the cell fills |
| Pod temperature while charging | R4, R7 | Touch thermometer on the lid every 15 minutes | Never above 40 °C |
| Contacts dead when not charging | R7 | Meter across the receptacle contacts with the cell connected and no charger | 0 V (see safety stop S6) |
| Sample rate | R3 | Read the sensor's sample count against the module's clock over 60 s | 104 Hz within the firmware's correction |

## 6. Safety stops

Stop at each point. Carry on only when everything listed is true.

- **S1. Before the cell comes into the workshop.** The cell has its own protection circuit and a datasheet from its maker; its voltage is 3.0 to 4.2 V; it has no swelling, dents or leaks. A charging spot is ready on a non-combustible surface (a ceramic tile or steel tray), away from anything that burns.
- **S2. Before the cell's plug is cut.** Cut one lead at a time and tape the bare end at once; never let the two leads touch, and never cut both together with one snip.
- **S3. Before the module is powered from the cell.** Check with a meter, not by wire colour, that the cell's positive lead goes to the battery positive pad and the receptacle's positive lead, through the diode, to the 5 V pin. The diode's marked end faces the module (check with the meter's diode range: it reads about 0.2 to 0.4 V from the receptacle toward the module and open the other way). Every joint is covered.
- **S4. Before the first charge.** The firmware has selected the 50 mA setting (or the module's default is confirmed as 50 mA). The first charge is attended the whole time, lid off, on the charging spot; the cell is checked by touch every 15 minutes. Stop if the cell becomes warm or swells. Never charge the band while it is worn.
- **S5. Before the lid goes on.** No wire crosses the gasket rim or presses on a sharp edge of the cell; the cell is seated flat in its pocket; nothing is pinched under the module.
- **S6. Before the band is worn.** The pod is closed and the screws are flush; the strap is held; the receptacle contacts read 0 V with no charger attached; the wearer understands this is a research and educational prototype, not a medical device. Check the skin under the band after the first hours of wear and stop if there is any redness, irritation or warmth.

## 7. Tools, skills and workspace

**Tools.** FDM 3D printer that prints PETG and TPU 95A (a direct-drive extruder makes TPU easier); pin vise with 1.0, 1.6 and 2.0 mm drills; sharp craft knife and cutting mat; 4 mm hole punch; fine saw and fine abrasive paper for the acrylic rod; temperature-controlled soldering iron with a fine tip, flux and thin solder; flush cutters and wire strippers for 26 AWG; heat gun or lighter for heat shrink; small Phillips driver for M2 screws; spring bar tool; multimeter; USB power meter; touch thermometer; calipers; scale reading to 0.1 g; mixing stick and cup for epoxy.

**Skills.** No certified trade is needed. Setting up a 3D print, careful hand drilling of small holes, fine soldering on small pads, and care with lithium cells. All circuits are extra-low voltage: 4.2 V at most at the cell and 5 V from the charging cable.

**Workspace.** A clean, well-lit bench about 0.6 x 0.4 m; a ventilated place for printing and soldering; the charging spot of S1.

**Personal protective equipment.** Safety glasses when cutting the cell's leads, soldering and drilling; nitrile gloves when mixing epoxy.

## 8. Where the numbers come from

- Model and constructability checks: `cad/src/model.py` (`python cad/src/model.py --check`, 38 checks); STEP and STL exports in `cad/step/` and `cad/stl/`.
- Pictures: `cad/src/build_plan_media.py`, using `.kit/build_views.py`; written to `docs/05-build-plan/` and `cad/drawings/TRT-DWG-101` to `TRT-DWG-104`.
- General arrangement: `cad/drawings/TRT-DWG-002.pdf`, Rev P3.
- Calculations: `docs/04-calcs/01-sizing.md` (TRT-CAL-001 v0.4) and `docs/04-calcs/sizing.py`; mass in section 7, charging in section 5.
- Bill of materials: `bom/bom.csv` and `bom/bom-notes.md`.
- Decisions: `docs/decisions/0003-design-for-construction.md` (TRT-DDR-003), with TRT-DDR-001 and TRT-DDR-002; open items in `docs/06-design-decisions.md` (TRT-DEC-001).
- Requirements: `docs/03-requirements.md` (TRT-REQ-001 v0.6).

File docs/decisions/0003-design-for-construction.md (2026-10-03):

---
doc_id: TRT-DDR-003
title: TremorTrace design for construction
project: TremorTrace
doc_type: Design decision record
version: "0.3"
status: Draft
date: '2026-10-02'
author: Amish Chadha
license: CERN-OHL-S-2.0
revisions:
- version: "0.1"
  date: '2026-10-02'
  author: Amish Chadha
  change: Changes that make the concept physically buildable, with the reason for each; made under Amish's 2026-09-30 instruction to make the design physically buildable; open for his review
- version: "0.2"
  date: '2026-10-02'
  author: Amish Chadha
  change: Accepted by Amish on 2026-10-02, with A1 (over-the-air updates) and A2 (Schottky diode on every band) decided
- version: "0.3"
  date: '2026-10-02'
  author: Amish Chadha
  change: 'A2 diode carried into the model, BOM and wiring picture; wiring description added'
---

# 0003: Design for construction

- **Date:** 2026-10-02
- **Status:** Draft; accepted. Amish, 2026-10-02: "APPROVED: The open decisions from the last wave (TremorTrace to ZeerBox) came in after the review and aren't on the page either." This approves the recommendation written for each open decision in the design decisions register (TRT-DEC-001 v0.1): every change in Tables 1 and 2 is accepted as made, and A1 and A2 in Table 3 are decided as recorded there.

> **Safety:** TremorTrace is a research and educational prototype, not a medical device. It carries a lithium polymer cell against the skin: use a protected cell, never charge while worn, and stop use if the pod becomes warm or swollen.

## Context

On 2026-09-30 Amish asked for every repo to have an illustrated prototype build plan and wrote: "If you are realising that the design cannot be built as per concept - fix the design assumptions to match and be physically feasible as you draw the illustrations." The TRL 3 model of TRT-DDR-002 showed what TremorTrace does and that it works on paper, but several parts could not be made or fixed as drawn. Checking the concept geometry with build123d (intersections and distances between parts) found the problems in Table 1.

The changes keep what the band does: the same 30 x 40 x 12 mm pod, the same module, cell, charging receptacle, light pipe, gasket, strap and spring bars, the same 22 mm lugs and the same sensing, storage, power and data path. Nothing here changes the pitch or the safety case. Every change is in `cad/src/model.py`, which now also runs 29 constructability checks (`python cad/src/model.py --check`): parts that must touch do touch, and parts that must not touch are apart by at least the stated clearance. All 29 pass.

## Decision

*Table 1. Changes made to the model, the BOM and the calculations.*

| # | Problem in the concept | Change made | Why this way |
| --- | --- | --- | --- |
| C1 | The spring bar holes were 1.8 mm across, larger than the 1.5 mm body of a 22 mm quick-release bar. The body could enter one hole, the other tip would then leave its hole, and the strap would fall off. | 1.0 mm tip holes drilled right through each lug horn, 2 mm from the end and 3 mm up. The bar body (1.5 mm) sits between the horns; only its 0.9 mm tips enter the horns, 1.5 mm deep. | This is how a watch with drilled lugs holds its bars. Through holes let the bar be pushed out with a pin to change the strap. |
| C2 | The two M2 lid screws sat on the centre line, directly above the strap notches. Their pilot holes ran down to the notch ceiling, leaving no plastic below the screw (0 mm), and the screw tip ended 0.85 mm from the strap loop. | Four M2 x 6 countersunk thread-forming screws, one in each lug horn (the solid corner beside each notch), 13 mm each side of the centre along the forearm and 2.6 mm in from the end. Each has 4 mm of thread in solid plastic, 2 mm above the spring bar hole. | The horns are the only solid material at full height. Four corner screws also squeeze the gasket at all four corners instead of two ends, which helps the splash seal (R7). Countersunk heads sit flush, so the pod stays 12 mm high, as the 2026-09-26 review recommended for the appearance model. |
| C3 | The strap end looped round the spring bar (a 1.4 mm strap round a 1.5 mm bar is 4.3 mm across) overlapped the inner face of the 4.0 mm deep notch by 0.15 mm. | Notch 4.5 mm deep (was 4.0). The loop now clears the notch face by 0.35 mm and the horns by 0.2 mm. | The smallest change that lets the strap swing. The cavity across the wrist shrinks from 29.6 to 28.6 mm, which still leaves the cell 0.3 mm clear. |
| C4 | The charging receptacle sat in a hole in the 1 mm floor with nothing to hold it or seal round it. | A printed collar, 0.8 mm thick and 2 mm high, round the opening on the inside of the floor. The receptacle is pushed up through the opening with its contacts flush underneath and set in two-part epoxy that fills the collar. | The collar gives the epoxy a cup to fill, so the joint is both the fixing and the seal at the one hole through the skin side of the pod. |
| C5 | Nothing located the cell: it could slide 6.95 mm along the forearm and 1.8 mm across. | Three ribs printed on the floor, 1.5 mm high and 1 mm wide: one at the charging end and one along each long side. With the end wall they make a pocket 0.3 mm larger than the cell all round. | No glue on the cell, so it can be lifted out; the wires run in the gaps beside it. |
| C6 | The module floated on its foam pad with a 1.7 mm gap to the lid. | An upper foam pad cut from 2 mm closed-cell foam, with a 4 mm hole over the status LED, which the lid squeezes to 1.7 mm. The lower 0.5 mm adhesive foam pad is now in the model too. | The lid clamps the whole stack (cell, pad, module, pad), so nothing rattles and no screw or bracket is needed inside. |
| C7 | The cell's plug (JST-PH, about 8 x 4.5 x 6 mm) has no room anywhere in the 9.5 mm high cavity beside the stack. | The plug is cut off one lead at a time and the leads are soldered to the module's battery pads. | The module has battery pads for exactly this; a plug-in cell is not needed in a sealed pod. |
| C8 | The light pipe was a bore in the lid with no part in it. | A 2 mm length of 2 mm clear acrylic rod, pushed in from underneath until flush with the top and set with clear epoxy; it stands 0.5 mm below the lid, 1.2 mm above the module. | The pipe is now in the model, so its clearance to the module and the foam is checked. |
| C9 | The gasket was drawn at its squeezed thickness only and had holes for two screws. | Printed 0.8 mm thick in TPU 95A, squeezed to 0.5 mm, with four screw holes. | A 0.5 mm ring would not seal once squeezed; 0.8 mm gives 0.3 mm of squeeze. |

*Table 2. Knock-on changes.*

| Item | Change | Reason |
| --- | --- | --- |
| Mass | 26.2 g (was 25.4 g), 3.8 g under the R6 limit of 30 g (TRT-CAL-001 v0.3, section 7). | Two more screws, the upper foam pad, epoxy, and the ribs and collar in the base. |
| Cost | BOM lines 2, 4, 5, 7, 8, 9 and 11 updated; line 9 is now four screws. Estimated cost of the constructable design: USD 43.79 (was USD 43.19 before construction, USD 43.69 before the diode), USD 106.21 under the USD 150 value-engineering target (`budget_usd`, unchanged). | Parts added for construction; line 12 (Schottky diode, USD 0.10) added on 2026-10-02. |
| Drawings | TRT-DWG-002 Rev P3 (was P2); making sketches TRT-DWG-101 to 104 added. | Follows the model. |
| Documents | TRT-CAL-001 v0.3, TRT-REQ-001 v0.5, TRT-PRC-001 v0.6: mass, cost and component figures updated. No requirement changed status. New: TRT-BLD-001 (build plan) and TRT-DEC-001 (design decisions register). | Follows the model. |
| Media | Concept media regenerated from the model (`cad/src/concept_media.py`). | Follows the model. |

*Table 3. Decided by Amish, 2026-10-02.*

| # | Question | Options | Recommendation |
| --- | --- | --- | --- |
| A1 | Once the lid is on, the module's USB-C socket is sealed inside the pod, so firmware cannot be loaded through it without opening the pod (and replacing the gasket). | (a) load firmware over Bluetooth with the nRF52840's over-the-air bootloader; (b) open the pod for each update. | (a), keeping (b) for recovery. **Decided by Amish, 2026-10-02: (a), with (b) for recovery only.** |
| A2 | The charging receptacle's two contacts touch the skin while the band is worn. They are wired to the module's 5 V and ground pins, which should carry no voltage when no charger is attached, but this depends on the module's circuit. | (a) confirm on the bought module that the 5 V pin is dead with the cell connected and no charger, and add nothing; (b) add a small Schottky diode in the receptacle's positive lead in any case. | (b), with (a) as a check: fit the diode on every band and still confirm the pin is dead; drop the diode only if measurements show the pin dead in every operating state. **Decided by Amish, 2026-10-02.** The diode is in the model (SOD-123 on the base floor beside the receptacle collar, 3.2 mm from the receptacle), the BOM (line 12) and the wiring picture (follow-up in `docs/REVIEW.md`, 2026-10-02). |

## Wiring as built in the model

The charging receptacle's red lead passes through a Schottky diode (SOD-123, 1.6 x 2.7 x 1.1 mm, marked end toward the module) on its way to the module's 5 V pin; the black lead goes straight to a ground pin. The diode lies on the base floor 8.5 mm to one side of the receptacle opening, 3.2 mm from the receptacle and 3.5 mm or more from the module and cell (checked in `cad/src/model.py`). The over-the-air bootloader is loaded through the module's USB-C socket before the lid is closed; opening the pod is for recovery only (A1).

## Consequences

- `design_state: constructable` in `project.yaml`. The build plan TRT-BLD-001 shows every component and step in pictures generated from the model (`cad/src/build_plan_media.py`).
- Requirement status is unchanged: nine met, two not verifiable at TRL 3 (R7, R8), none at risk, none not met (TRT-CAL-001 v0.3).
- The photoreal renders (`media/render-*.png`), `media/card.png`, `media/social-preview.png` and the appearance model `cad/src/product_model.py` still show two pan-head lid screws on the centre line. They need updating on Amish's Mac, where Blender is.
- The module's status LED position, its height and the charging receptacle's size are assumed; they are confirmed when parts are bought (TRT-DEC-001).
- TRL 4 remains on hold by Amish's instruction; nothing was built, bought or tested.

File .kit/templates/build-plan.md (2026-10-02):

---
doc_id: PRJ-BLD-001
title: Project prototype build plan
project: Project name
doc_type: Build plan
version: "0.1"
status: Draft
date: YYYY-MM-DD
author: Amish Chadha
license: CERN-OHL-S-2.0
revisions:
  - version: "0.1"
    date: YYYY-MM-DD
    author: Amish Chadha
    change: First build plan; design made constructable
---

# Project prototype build plan

**Plan, not yet built.** How to build the first proof-of-concept prototype, component by component. Building and testing to it is TRL 4 work. Decisions still to be made are kept in the design decisions register (`docs/06-design-decisions.md`), not here.

## 1. What you are building

Every component, pulled apart and numbered in build order

One short paragraph: what the prototype is, how many components, which are made and which are bought, and the main ways they are made.

## 2. What changed to make it buildable

| Component | The concept had | The buildable design has | Why |
| --- | --- | --- | --- |

## 3. Making the components

### 3.1 Component name

Making sketch

**What it is and what it is made from.**

**How to make it.**

1. Mark out ...
2. Cut ...

**How it fits the parts next to it.**

Close-up of the joint

**Check before moving on.**

## 4. Putting it together

### Step 1: ...

Step 1

## 5. First checks

| Check | Requirement | How | Pass when |
| --- | --- | --- | --- |

## 6. Safety stops

## 7. Tools, skills and workspace

## 8. Where the numbers come from

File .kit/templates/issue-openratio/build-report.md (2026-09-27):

---
name: Build report
about: Tell us what happened when you built, printed or tested part of this design
title: "Build report: "
labels: build-report
---

This is a research and educational prototype, not a medical device. It is a TRL 3 concept and is not released for fabrication. If you build any part of it, you do so at your own risk. Reports help everyone.

**What you built** (part, sub-assembly or test)

**Materials, tools and settings**

**What worked**

**What did not work, with photos or measurements if you have them**

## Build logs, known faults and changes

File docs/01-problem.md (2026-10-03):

---
doc_id: TRT-PRB-001
title: TremorTrace problem statement
project: TremorTrace
doc_type: Problem statement
version: "0.4"
status: Draft
date: '2026-10-02'
author: Amish Chadha
license: CERN-OHL-S-2.0
revisions:
- version: "0.1"
  date: '2026-09-24'
  author: Amish Chadha
  change: Initial scaffold
- version: "0.2"
  date: '2026-09-24'
  author: Amish Chadha
  change: Populate to TRL 2 (users, context, constraints, prior work)
- version: "0.3"
  date: '2026-09-25'
  author: Amish Chadha
  change: Wrist question closed per TRT-DDR-001; partner question stays open
- version: "0.4"
  date: '2026-10-02'
  author: Amish Chadha
  change: Partner question answered by Amish's decision of 2026-10-02 (TRT-DEC-001)
---

# TremorTrace problem statement

Tremor is judged from a few minutes of observation in a clinic, but it changes through the day with medication timing, fatigue, stress and activity, so the snapshot a clinician sees is often not the tremor a person lives with.

## The problem

People with Parkinson's disease and essential tremor are typically assessed with rating scales (for example the MDS-UPDRS tremor items or TETRAS) during an appointment every few months. Those scores depend on what happens in the room that day. Patients are asked to recall how their tremor behaved between visits, and recall is poor. Medication changes are therefore judged on thin evidence.

Research has shown that a wrist-worn accelerometer and gyroscope can measure tremor frequency and amplitude continuously at home ([Mahadevan et al., npj Digital Medicine](https://www.nature.com/articles/s41746-019-0217-7); [standardized accelerometry method, PMC](https://pmc.ncbi.nlm.nih.gov/articles/PMC9386269/); [rest tremor from the wrist, PMC](https://pmc.ncbi.nlm.nih.gov/articles/PMC11942689/)). Commercial systems exist, but they are closed, costly, or tied to one phone ecosystem. There is no open, low-cost, inspectable reference design that a researcher, clinic or patient group can build, audit and adapt.

## Users and context

| User | Need | Context |
| --- | --- | --- |
| Person living with tremor | Wear it all day without thinking about it; see how tremor changed and share it | At home, daily activities, 12 to 16 h of wear |
| Care partner | Understand good and bad periods of the day | Home |
| Clinician or researcher | Objective daily tremor profile between visits, in a format they can analyze | Clinic review, research studies |
| Open hardware community | A reproducible design and analysis pipeline to build on | Makerspaces, university labs |

## Constraints

- Garage-buildable prototype, about $150 USD per unit, using off-the-shelf modules and 3D-printed parts.
- Comfortable for all-day wear: light, small, skin-safe materials.
- Health data is sensitive: data stays on the device and the owner's phone by default; the owner controls any sharing.
- Research and educational use only. TremorTrace is not a medical device and must not be used to diagnose, treat or change medication.

## Out of scope

- Diagnosis or classification of disease.
- Tremor suppression or stimulation.
- Cloud services.

## Open questions

- Which users to involve first, and through which partner (a movement disorders clinic, a patient association, or OpenRatio's network)? Decided by Amish, 2026-10-02 (TRT-DEC-001): the first candidate to approach is an academic movement disorders clinic with its own ethics board, introduced through the OpenRatio network, with the International Essential Tremor Foundation as the route to participants, shared with StillBand and SteadySleeve; not yet approached.
- One wrist or both: closed. Decided by Amish, 2026-09-25 (TRT-DDR-001): the most affected wrist first, both wrists later.

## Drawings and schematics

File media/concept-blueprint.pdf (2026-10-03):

CONCEPT, NOT FOR FABRICATION | TremorTrace · github.com/BoujeeEnjinia1701/tremortrace

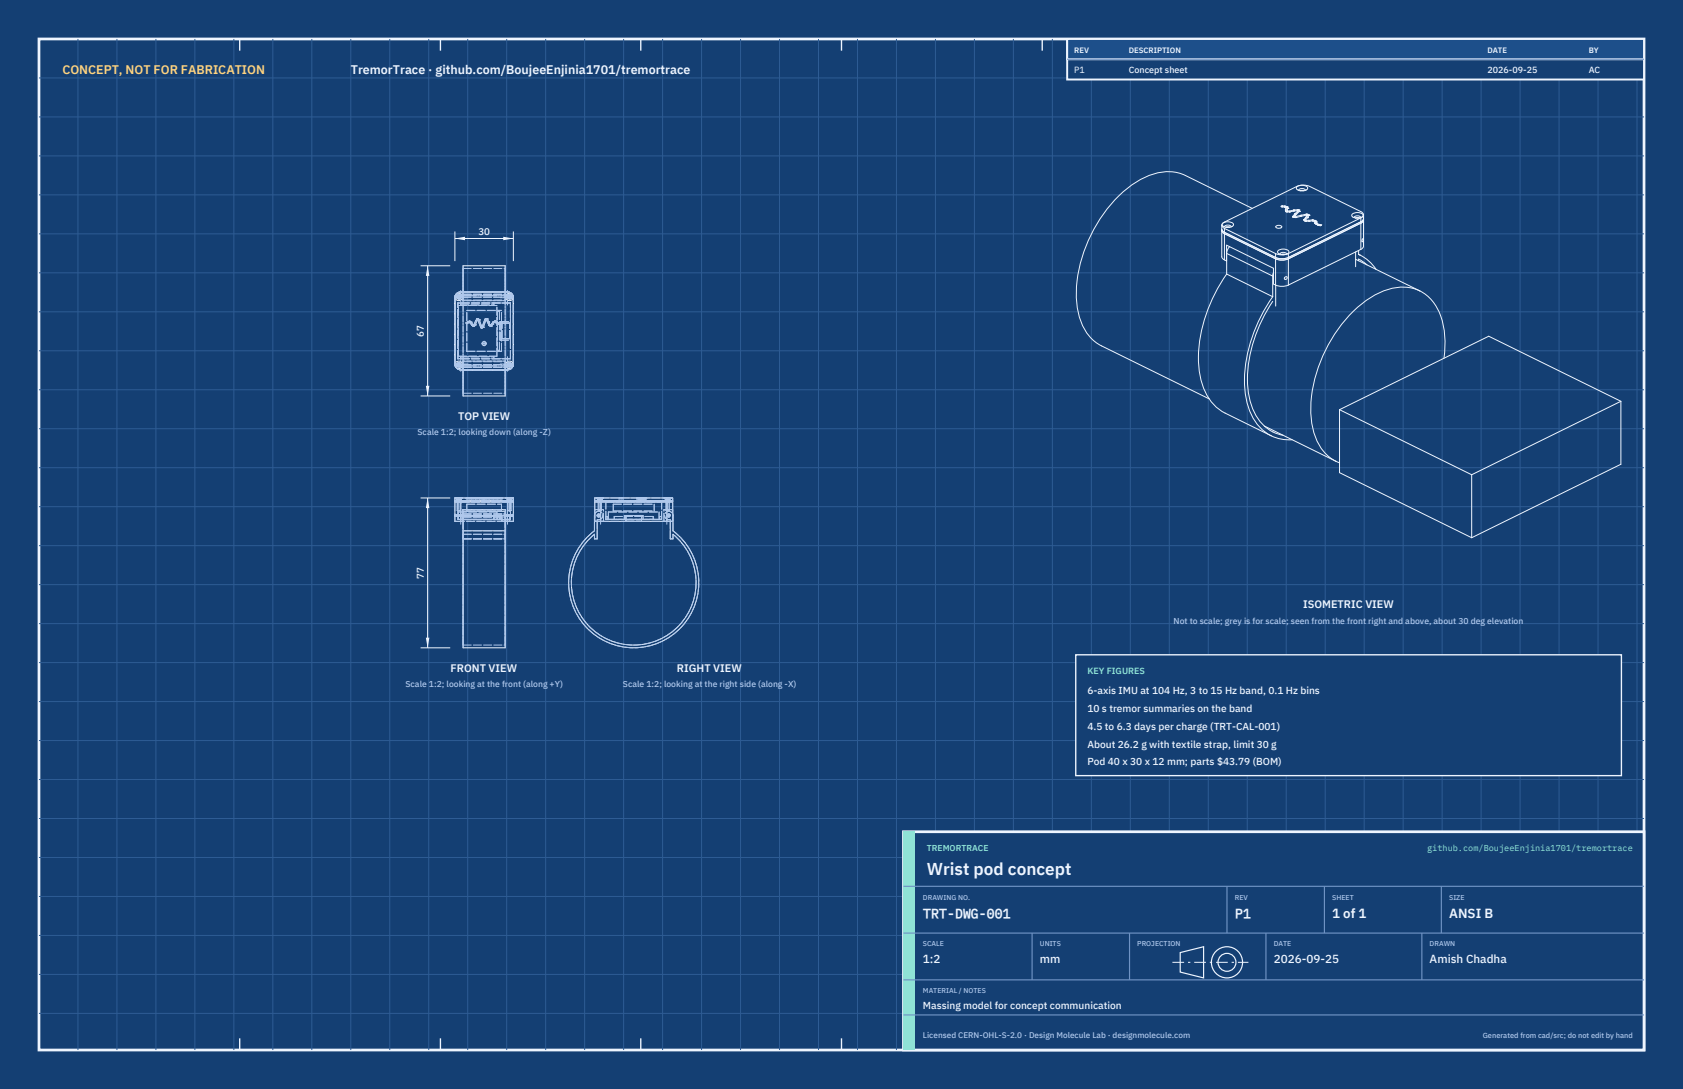
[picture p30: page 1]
FRONT VIEW; TOP VIEW; RIGHT VIEW; ISOMETRIC VIEW; REV; DESCRIPTION; DATE; Concept sheet; TREMORTRACE; github.com/BoujeeEnjinia1701/tremortrace; DRAWING NO. TRT-DWG-001; REV P1; SHEET 1 of 1; SIZE ANSI B; SCALE 1:2; UNITS mm; PROJECTION; DRAWN Amish Chadha; Licensed CERN-OHL-S-2.0 · Design Molecule Lab · designmolecule.com; Generated from cad/src; do not edit by hand

Scale 1:2; looking down (along -Z)

Not to scale; grey is for scale; seen from the front right and above, about 30 deg elevation

KEY FIGURES
6-axis IMU at 104 Hz, 3 to 15 Hz band, 0.1 Hz bins
10 s tremor summaries on the band
4.5 to 6.3 days per charge (TRT-CAL-001)
About 26.2 g with textile strap, limit 30 g
Pod 40 x 30 x 12 mm; parts $43.79 (BOM)

Scale 1:2; looking at the front (along +Y)

Scale 1:2; looking at the right side (along -X)

Wrist pod concept

MATERIAL / NOTES
Massing model for concept communication

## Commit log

2026-09-24 Initial scaffold: standard open hardware layout, CERN-OHL-S v2 + MIT licenses
    Claude-Session: https://claude.ai/code/session_01XuhhSU4W6fYhgCfURbrkut
    [bom.csv]
2026-09-25 Adopt portfolio kit v1.3.0: session commands, scale figure, 3D viewer, flow diagrams
    Adds .claude/commands (/populate, /advance-trl3, /rein-in, /refresh-media)
    so every Claude Code session starts from the standard prompts, and extends
    concept media with a 1.75 m scale figure, an interactive glTF viewer and
    system or energy flow diagrams. TRL cap 3 unchanged.
    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
2026-09-25 Populate TremorTrace to a strong TRL 2 with concept media
    - TRT-PRB-001, TRT-REQ-001, TRT-PRC-001 v0.2: users, 11 measurable
    requirements, architecture, first-order numbers, safety
    - Massing model and media: hero, blueprint, cutaway, exploded view,
    data flow, interactive 3D viewer
    - Indicative BOM (about $40 in parts) and docs/REVIEW.md with five
    decisions proposed and awaiting Amish
    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
    [bom.csv]
2026-09-25 Kit v1.3.1: renderer fixes from the TremorTrace pilot
    Context scale parts for small objects, cutaway exclusions, and text
    labels in flow diagrams.
    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
2026-09-25 Review fixes: close the massing pod, renumber TRT-DWG-001, mark choices proposed
    At Amish's request, after reviewing 15c42b7 and 5091eea:
    - concept_media.py: base walls now enclose the cell and module; pod is
    12.0 mm overall as in TRT-PRC-001 (was open-sided, 13.5 mm). Media
    regenerated.
    - Concept sheet renumbered TRT-DWG-001 (was TRT-DWG-010).
    - TRT-PRC-001 v0.3: one-module and local-first choices marked
    "Proposed, awaiting Amish".
    - docs/REVIEW.md records the fixes and what still awaits Amish.
2026-09-25 Advance tremortrace to TRL 3 (batch 1)
    Decisions approved by Amish 2026-09-25 recorded in DDR-001. TRL 4 is on hold.
    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
    [bom.csv, tremortrace-base.step, tremortrace-base.stl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]
2026-09-26 Accept all recommendations (DDR-002), switch footer to designmolecule.com, add README write-up with new inspiration point
    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
    [bom.csv, tremortrace-base.step, tremortrace-gasket.step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]
2026-09-27 Product appearance model and photoreal renders
    Adds cad/src/product_model.py (appearance model for renders only, all main
    dimensions from model.py) and Blender renders in media/render-*.png,
    captioned with the project, repository and viewing direction. README leads
    with the product render; trl stays 3.
    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
2026-10-01 Image quality pass: legible exploded views, flow diagrams and drawing sheets
    Kit 1.6.1 image layout: the parts list sits in its own column, number bubbles sit on visible parts and never overlap, small parts get a leader, pictures are cropped to the subject, flow labels keep numbers with their units, and sheet captions and the revision table no longer overprint. Concept images, blueprint and general arrangement sheet regenerated; repo-specific labels moved clear of other text and lines.
2026-10-02 Kit 1.7.0: constructable design, illustrated build plan and design decisions register
    The design is now constructable: every part can be made and fits its neighbours, with each change recorded in a Design for construction decision record (made under Amish's 2026-09-30 instruction; ope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
    FlexHand also credits Dr. Geeti Chadha as a contribut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
    [bom.csv, tremortrace-base.step, tremortrace-base.stl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]
2026-10-03 Carry approved follow-ups into the design and redo photoreal renders
    Amish approved the follow-up actions from the open-decision sign-off ("APPROVED CHANGES, COMPLETE THESE", 2026-10-02), the design-for-construction change tables in ten repos, the last wave's open dec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
    [bom.csv, tremortrace-base.step, tremortrace-gasket.step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]

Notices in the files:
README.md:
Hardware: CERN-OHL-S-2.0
